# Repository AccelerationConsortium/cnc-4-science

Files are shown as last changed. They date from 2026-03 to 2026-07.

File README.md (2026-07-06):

<h1>cnc-4-science</h1>

<table>
  <tr>
    <td align="center" width="50%">
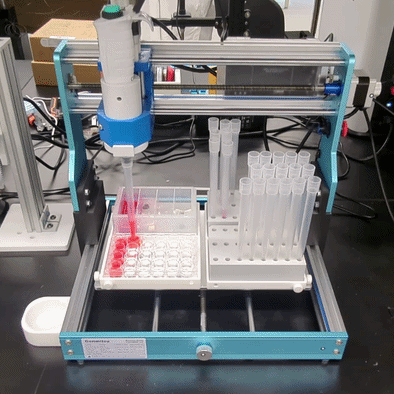
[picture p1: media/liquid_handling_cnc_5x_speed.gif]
Liquid handling demo (5x speed) — click to watch full video
      
      <br/><sub><a href="examples/liquid_handling/">Liquid handling</a> · <a href="https://youtu.be/hJAHL1_uhBs">full video</a></sub>
    </td>
    <td align="center" width="50%">
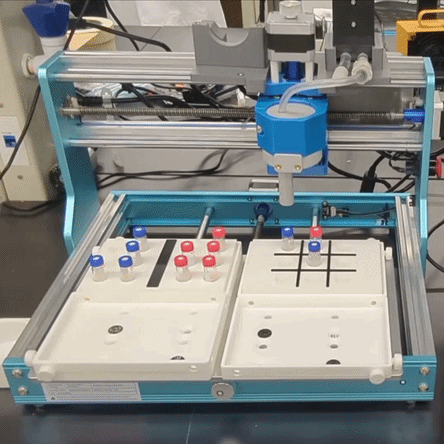
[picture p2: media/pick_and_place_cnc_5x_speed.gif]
Pick-and-place demo (5x speed) — click to watch full video
      
      <br/><sub><a href="examples/vacuum_pick_and_place/">Pick and place</a> · <a href="https://youtu.be/-8ptOuS6o5s">full video</a></sub>
    </td>
  </tr>
</table>

`cnc-4-science` is a Python control library for **low-cost, easy-to-assemble,
open-source GRBL CNC routers** used as the gantry for scientific automation.
The target hardware is the kind of CNC a scientist can buy off the shelf for
a few hundred dollars, put together over a weekend, modify with 3D-printed
parts, and drive from Python — no proprietary controller, no vendor SDK, no
custom firmware. The reference examples in this repo run on a Genmitsu
3018-PROVer V2, but the library is GRBL-generic and works on any equivalent
machine.

It's the foundation for building things like **liquid handling** and
**pick-and-place of vials / consumables / small parts** (the two shipped
examples), and any other workflow that fits the pattern "move this tool to
that well and do something." Each module is built around a 3-step workflow:

| 1. Install a tool | 2. Configure the deck | 3. Write the workflow in Python |
| --- | --- | --- |
| Design and install your instrument on the CNC carriage -- a pipette, a vacuum gripper, a fraction needle, whatever the workflow needs. The mechanical interface is a 3D-printed bracket; the rest is up to the tool. | Decide what labware and external modules sit on the deck and where. Describe it in YAML -- standard SBS plates and tipracks via [Opentrons](https://labware.opentrons.com/#/create) definitions, or open / custom JSON for larger external modules that don't fit the SBS footprint. | Write a Python protocol against `cnc_machine_core` and a thin tool wrapper. The two YAML files (`tools/cnc_config.yaml` + `tools/<tool>_config.yaml`) hold every setup-specific number; the protocol stays portable. |

```bash
pip install cnc-4-science
```

See [`examples/README.md`](examples/README.md) for the standard 3-step user
journey every example follows. To bootstrap a brand-new CNC module with an
LLM coding agent, point it at [`examples/AGENTS.md`](examples/AGENTS.md) --
it documents the directory layout, config schema, and tool-wrapper contract
that every example follows.

---

## Reference applications

| Example | Tool | Workflow | Sample workflow video |
| --- | ---- | --- | --- |
| [`hello_cnc/`](examples/hello_cnc/) | Stock spindle | Home, move, spindle on/off — the hardware smoke test | |
| [`liquid_handling/`](examples/liquid_handling/) | Sartorius Picus 2 pipette | Serial dilution across a 24-well plate | [YouTube](https://youtu.be/hJAHL1_uhBs) |
| [`vacuum_pick_and_place/`](examples/vacuum_pick_and_place/) | Vacuum gripper (spindle-driven) | Physical tic-tac-toe — CLI + optional browser UI | [YouTube](https://youtu.be/-8ptOuS6o5s) |

---

## Quick start

```bash
# 1. Pick an example and read its README + ASSEMBLY_INSTRUCTIONS.md.
#    Order/print the parts and assemble the hardware.

# 2. From the example folder:
python -m venv .venv
.\.venv\Scripts\Activate.ps1     # Windows
# source .venv/bin/activate      # Linux / macOS
pip install -r requirements.txt

# 3. Edit tools/cnc_config.yaml (COM port, travel bounds) and the tool config.
#    See docs/SETUP.md §0 for how to find the serial port on Windows / macOS / Linux
#    and how to measure your CNC's travel envelope.

# 4. Run the protocol.
python protocols/<name>.py
```

> First time setting up a new CNC? Run
> [`examples/hello_cnc/hello_cnc.py`](examples/hello_cnc/) once to verify the
> gantry homes, jogs, and toggles the spindle. You don't need to re-run it
> for every protocol.
>
> Each example's `tools/cnc_config.yaml` ships with `z_heights:` calibrated
> for the reference build in its `ASSEMBLY_INSTRUCTIONS.md`. If your build
> differs, remeasure by hand — see
> [docs/SETUP.md §4](docs/SETUP.md#4-calibrate-z-heights).

> **New to the library?** Read [docs/SETUP.md](docs/SETUP.md) for the
> long-form software walkthrough (deck → labware → toolhead/driver →
> tool offsets → Z calibration → protocol).
>
> **Building your own application?** Copy [`examples/liquid_handling/`](examples/liquid_handling/)
> or [`examples/vacuum_pick_and_place/`](examples/vacuum_pick_and_place/) as
> a template — the conventions are documented in
> [`examples/AGENTS.md`](examples/AGENTS.md).

---

## API reference

### Motion

| Method | Description |
|---|---|
| `home()` / `origin()` | Home and park; or move to origin without homing. |
| `connect()` / `close()` | Open / close the serial connection to the controller. |
| `move_to_point(x, y, z)` | Absolute move (XYZ in mm). |
| `move_to_point_safe(x, y, z)` | Raise Z to clearance, move XY, lower Z. Prevents collisions with labware. |
| `move_to_point_safe_orthogonal(x, y, z, waypoint, axis_order)` | One-axis-at-a-time waypoint move (`yxy`, `xyx`, `xyxy`, `yxyx`). |
| `move_to_location(location, index)` | Move to a named position from `location_status.yaml`. |
| `spindle_on(rpm)` / `spindle_off()` | `M3` / `M5`. Doubles as the on/off for vacuum or solenoid tools wired to the spindle terminals. |
| `is_alarm()` / `recover_if_alarm()` | Alarm-state check + auto-rehome. Called internally before every move. |

### Deck and labware

The `cnc_deck` module provides `Well`, `Labware`, and `Deck` objects for
coordinate resolution:

```python
from cnc_machine_core import Deck
from opentrons_shared_data.labware import load_definition

deck = Deck("cnc_4_slot_deck")                               # built-in 4-slot deck (Genmitsu 3018)

# Standard SBS labware: load by Opentrons load name (no JSON file of your own).
plate = deck.load_labware_definition(
    "1", load_definition("corning_96_wellplate_360ul_flat", 1)
)

# Or a custom JSON for non-SBS gear (see custom_labware/ in the examples):
# plate = deck.load_labware("1", "custom_labware/my_rack.json")

x, y, z = plate["A1"].position()                             # absolute CNC coordinates
```

Protocols add the tool's XY offset at the call site —
`plate["A1"].position(offset=tool.offset)` — see
[`examples/liquid_handling/protocols/serial_dilution_demo.py`](examples/liquid_handling/protocols/serial_dilution_demo.py)
or [`examples/vacuum_pick_and_place/game_session.py`](examples/vacuum_pick_and_place/game_session.py)
for the live pattern.

Built-in decks — pick one explicitly (there is no default; the CNC footprint
should be visible at the call site):

- `cnc_4_slot_deck` — standard 4-slot (2×2), sized for the Genmitsu
  3018-PROVer V2 (~300×180 mm bed). Larger CNCs (3040, 6040, …) will likely
  want a custom deck with more slots — copy the JSON and re-measure the
  slot corners.
- `cnc_1_slot_deck` — single open slot at origin (no labware required)

Labware definitions are created with the
[Opentrons Labware Creator](https://labware.opentrons.com/#/create) — only
the XY well coordinates are used. Z heights are calibrated empirically per
(tool, labware, action) because they depend on the tool mount and labware
seating, not the labware geometry alone. See
[docs/SETUP.md §4](docs/SETUP.md#4-calibrate-z-heights).

### Direct positioning (no labware)

For simple setups, use the open deck and move to raw coordinates:

```python
from cnc_machine_core import Deck

deck = Deck("cnc_1_slot_deck")
cnc.move_to_point_safe(x=100, y=50, z=-20)
```

Regular grids without named wells can be described in YAML and addressed by
index via `move_to_location()`:

```yaml
vial_rack:
  num_x: 2          # columns
  num_y: 4          # rows
  x_origin: 166.5
  y_origin: 125
  z_origin: 0
  x_offset: 36
  y_offset: -36
```

The location index walks a full column before advancing.

vial_rack

### Deck state

The `deck_state` module tracks per-well status across all slots with YAML
persistence:

```python
from cnc_machine_core import DeckState

ds = DeckState()
ds.init_wells_from_labware("1", plate)
ds.init_from_preset({"1": {"A1": "sample"}})
ds.set_status("1", "A1", "processed")                # auto-saves
loc = ds.find_next(["1", "2"], "sample")             # ("1", "A2")
ds.count(["1"], "processed")
ds.summary()
```

Status strings are application-defined. A sample preset is in
[`examples/liquid_handling/deck_preset.yaml`](examples/liquid_handling/deck_preset.yaml).

### Z calibration

Z heights live in `tools/cnc_config.yaml` under `z_heights:` and are measured
empirically per `(tool, labware, action)` — see
[docs/SETUP.md §4](docs/SETUP.md#4-calibrate-z-heights). Each shipped example
includes calibrated values for its reference build; remeasure by hand if
yours differs.

### Tool wrapper contract

Every tool class follows the same shape, so the protocols read the same way
across examples:

```python
class MyTool:
    def __init__(self, cnc_machine, tool_config):
        self.cnc = cnc_machine
        self.offset = tool_config.get("offset", {"x": 0, "y": 0, "z": 0})
        # extract parameters from tool_config["parameters"]
```

See
[`examples/liquid_handling/tools/picus_pipette.py`](examples/liquid_handling/tools/picus_pipette.py)
for a wrapper around a vendor serial driver, and
[`examples/vacuum_pick_and_place/tools/vacuum_gripper.py`](examples/vacuum_pick_and_place/tools/vacuum_gripper.py)
for a wrapper that drives the CNC's spindle terminals directly (no separate
serial port).

---

## Authors and acknowledgements

Authors: Owen Melville, Kelvin Chow.

CNC-based scientific instruments inspired by the
[Keith Brown Lab](https://sites.bu.edu/kablab/) [[1]] [[2]].

[1]: https://doi.org/10.1039/D4MH00797B
[2]: https://doi.org/10.1016/j.ohx.2024.e00601

## License

GNU General Public License v3.0 or later. See [LICENSE](docs/LICENSE).

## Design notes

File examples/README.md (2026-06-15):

# Examples

Reference projects that exercise `cnc_machine_core` end-to-end. Use these as
**templates** when building your own application — copy the closest match and
edit it.

| Example | Hardware | Software |
| --- | --- | --- |
| [`hello_cnc/`](hello_cnc/) | [ASSEMBLY_INSTRUCTIONS.md](hello_cnc/ASSEMBLY_INSTRUCTIONS.md) (~1 hr) — base CNC only | [README](hello_cnc/README.md) — **first-time CNC sanity check** |
| [`liquid_handling/`](liquid_handling/) | [ASSEMBLY_INSTRUCTIONS.md](liquid_handling/ASSEMBLY_INSTRUCTIONS.md) (~1 hr) | [README](liquid_handling/README.md) |
| [`vacuum_pick_and_place/`](vacuum_pick_and_place/) | [ASSEMBLY_INSTRUCTIONS.md](vacuum_pick_and_place/ASSEMBLY_INSTRUCTIONS.md) (~1 hr) | [README](vacuum_pick_and_place/README.md) |

## Standard user journey

Every example follows the same 3-step flow — pick one and follow its README:

1. **Hardware setup (~1 hr)** — order/print parts (BOM in `ASSEMBLY_INSTRUCTIONS.md`),
   wire the tool, mount the deck.
2. **Software setup** — `python -m venv .venv` → activate → `pip install -r requirements.txt`.
3. **Configure & run** — edit `tools/cnc_config.yaml` (COM port, bounds) and the
   tool config, then run the protocol in `protocols/`.

> [`hello_cnc/`](hello_cnc/) is a **first-time CNC sanity check** (homes,
> jogs, toggles the spindle) — run it once when you set up a new machine.
> The other examples don't depend on it.
>
> The `z_heights:` shipped in each example's `cnc_config.yaml` are calibrated
> for the reference build in its `ASSEMBLY_INSTRUCTIONS.md`. If you reproduce
> that build exactly, leave them alone; if anything differs (tip length, deck
> shim, mount), remeasure by hand and edit `z_heights:` — see
> [docs/SETUP.md §4](../docs/SETUP.md#4-calibrate-z-heights).

To create a new example, follow [AGENTS.md](AGENTS.md) — it documents the
shared layout, config schema, driver-class pattern, and the conventions all
of the above follow.

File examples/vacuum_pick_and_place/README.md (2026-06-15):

# Vacuum Pick-and-Place — Physical Tic-Tac-Toe (CLI)

Plays tic-tac-toe on a real 3×3 board using a CNC gantry and a vacuum gripper.
Pieces are picked from a storage rack (X and O reservoirs) and placed on the
game board, one move at a time. The same gripper returns every piece to
storage at end-of-game.

Two-player or 1-player vs AI (Easy / Medium / Hard).

This example doubles as a **template for any vacuum-driven pick-and-place
workflow** — the gripper is just a thin wrapper around the CNC's spindle
output (M3/M5), so swapping in any electromagnet, gripper, or solenoid that
the controller can switch is a one-file change.

---

## 1. Hardware setup

See [ASSEMBLY_INSTRUCTIONS.md](ASSEMBLY_INSTRUCTIONS.md) for the full BOM,
print list, wiring, and step-by-step build. Come back here when the gantry is
mounted, the deck is squared, the vacuum gripper is wired, and the pump turns
on when GRBL sends `M3`.

## 2. Software setup

```bash
# 1. Create + activate a virtual environment
python -m venv .venv
.\.venv\Scripts\Activate.ps1     # Windows
# source .venv/bin/activate      # Linux / macOS

# 2. Install dependencies
pip install -r requirements.txt
```

Edit the two config files in [`tools/`](tools/):

- [`tools/cnc_config.yaml`](tools/cnc_config.yaml) — CNC COM port, travel bounds, Z heights, deck layout.
- [`tools/vacuum_config.yaml`](tools/vacuum_config.yaml) — vacuum RPM, settle delays, XY offset. **No separate port** — the vacuum pump is wired into the GRBL spindle output, so it shares the CNC's serial connection.

> **Finding the CNC COM port.** The GRBL board enumerates as a USB-to-serial
> device when plugged in. Unplug, list the ports, plug it back in, and list
> again — the new entry is the CNC.
>
> - **Windows**: `Get-CimInstance Win32_SerialPort | Select DeviceID, Name`
>   in PowerShell, or open Device Manager → *Ports (COM & LPT)* and look
>   for `USB-SERIAL CH340 (COMx)` / `Silicon Labs CP210x (COMx)`.
> - **macOS**: `ls /dev/tty.* | grep -Ei 'usbserial|wchusbserial'`. CH340
>   boards may need the [WCH driver](https://www.wch-ic.com/downloads/CH34XSER_MAC_ZIP.html).
> - **Linux / Raspberry Pi**: `ls /dev/ttyUSB* /dev/ttyACM*`. Add your user
>   to the `dialout` group to avoid `sudo`.
>
> Full walkthrough + driver links: [docs/SETUP.md §0](../../docs/SETUP.md#finding-the-serial-port-windows--macos--linux).

> Set `virtual: true` in `cnc_config.yaml` to dry-run the protocol without
> any hardware connected.

> The shipped `z_heights:` (`pick: -21.0`, `place: -19.0`) are calibrated for
> the reference build in [ASSEMBLY_INSTRUCTIONS.md](ASSEMBLY_INSTRUCTIONS.md).
> If your build differs, remeasure by hand — jog Z until the suction cup just
> kisses the top of a storage piece (→ `pick`) and just above a board cell
> rim (→ `place`), then edit `z_heights:`. See
> [docs/SETUP.md §4](../../docs/SETUP.md#4-calibrate-z-heights).

## 3. Run

```bash
python protocols/tic_tac_toe.py
```

The CLI prompts for game mode and accepts cell labels `A1`..`C3`. Commands
during play:

| Input | Effect |
| --- | --- |
| `A1`..`C3` | Place at that cell |
| `reset` | Return every placed piece to storage |
| `quit` | Exit; optionally reset board first |

Deck state is auto-saved to `output/deck_state.yaml` after every move, so
a crashed game resumes from the last known state.

### Optional: browser UI

A lightweight FastAPI frontend drives the same `GameSession` as the CLI (same
lock, same hardware handles, same state) — you cannot accidentally drive the
gantry from both at once.

```bash
uvicorn web.app:app --host 0.0.0.0 --port 8000
```

Then open <http://localhost:8000/>. 3×3 clickable board with mode / difficulty
/ symbol selectors, reset button, AI peek-and-play handshake (board flashes
the next CNC move before the gantry executes), and a collapsed debug bar with
the API request log. `virtual: true` works exactly the same way — the browser
drives the full game loop, just without any actual motion.

---

## Reference

### Deck layout

| Slot | Position | Role | Labware |
| ---- | --- | --- | --- |
| 1 | front-left  | *(empty)*  | |
| 2 | front-right | *(empty)*  | |
| 3 | back-left | `storage`  | `storage_15_tuberack_100ul` |
| 4 | back-right  | `gameboard`| `gameboard_15_tuberack_100ul` |

Storage rack (slot 3): O pieces in columns 1-2, X pieces in columns 4-5
(see `STORAGE_WELLS` in [game_logic.py](game_logic.py)).

Game board (slot 4): 3×3 play area occupies columns 2-4 of the 15-well rack
(see `BOARD_WELL_MAP` in [game_logic.py](game_logic.py)).

Slot assignment lives in [tools/cnc_config.yaml](tools/cnc_config.yaml) under
`deck:` — change it there, not in the protocol.

### What's different from the liquid handling demo

| Aspect | Liquid handling | This example |
| --- | --- | --- |
| Tool | Sartorius Picus 2 pipette | Vacuum gripper (suction cup on spindle) |
| Tool comms | Separate serial port (`COM3`) | **None** — uses CNC's spindle output |
| Tool wrapper | [`PicusPipette`](../liquid_handling/tools/picus_pipette.py) calls vendor driver | [`VacuumGripper`](tools/vacuum_gripper.py) calls `cnc.spindle_on()` / `cnc.spindle_off()` |
| Tool config | port, baud, volumes | RPM, settle delays (no port) |
| Labware | Opentrons standard + custom tiprack | Two custom 15-well racks (storage + board)  |
| Workflow | Linear (prefill → dilute) | **Interactive** — CLI prompts for moves |

### Directory layout

```
vacuum_pick_and_place/
├── README.md
├── ASSEMBLY_INSTRUCTIONS.md
├── requirements.txt
├── game_logic.py                       # board + AI (pure Python, no CNC)
├── game_session.py                     # shared state machine (CLI + web)
├── app_runtime.py                      # config loading + CNC/gripper bootstrap
├── protocols/
│   └── tic_tac_toe.py                  # CLI entry point (thin loop over GameSession)
├── web/
│   ├── app.py                          # FastAPI: /api/state | /start | /move | /ai-move | /reset
│   └── static/
│       ├── index.html
│       ├── game.js
│       └── style.css
├── tools/
│   ├── cnc_config.yaml                 # CNC + deck layout + Z heights
│   ├── vacuum_config.yaml              # vacuum: RPM, delays, offset
│   └── vacuum_gripper.py               # VacuumGripper wrapper (uses CNC spindle)
├── presets/
│   └── ttt_preset.yaml                 # initial deck state (X/O storage, empty board)
├── custom_labware/
│   ├── storage_15_tuberack_100ul.json
│   └── gameboard_15_tuberack_100ul.json
└── output/                             # state files written here at runtime
```

### Using this as a template

To adapt for a different vacuum/spindle-switched tool:

1. **Copy this folder** to a new directory.
2. **Edit `tools/vacuum_gripper.py`** if your "tool" semantics differ (e.g.
   electromagnet → rename methods to `magnet_on` / `magnet_off`, keep the
   `cnc.spindle_on/off` underneath).
3. **Add a tool config.** Update `tools/vacuum_config.yaml` with the on-value
   (RPM / PWM duty), any settle delays, and the XY/Z mount offset.
4. **Edit `cnc_config.yaml`.** Update `deck:` slot roles + labware comments
   to match your deck. Measure Z heights by hand (jog with a GRBL UI like
   [Candle](https://docs.sainsmart.com/article/bj9o96wcbc-how-to-set-up-use-candle-for-multiple-operations)
   or `cnc.move_to_point(...)` from a Python shell) and write them into
   `z_heights:` — see [docs/SETUP.md §4](../../docs/SETUP.md#4-calibrate-z-heights).
5. **Write your protocol** in `protocols/`. The `_pick_and_place()` helper in
   [game_session.py](game_session.py) is a one-screen reference. If you also
   want a web UI, copy [web/app.py](web/app.py) — the FastAPI layer is
   ~100 lines and reuses whatever `GameSession`-style state machine you build.

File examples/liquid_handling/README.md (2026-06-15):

# Liquid Handling — Serial Dilution (Sartorius Picus 2)

1:2 serial dilution across a 24-well plate using a Sartorius **Picus 2** 5000 µL pipette on a Genmitsu CNC machine.

This folder doubles as a **template** for building your own CNC-based protocols — copy it, swap the tool, edit the configs.

- **Phase 1 — Prefill.** Pick up a tip, prefill 23 wells (`B1..D6`) with diluent from reservoir A2 (batched aspirations), discard tip.
- **Phase 2 — Dilute.** Pick up a new tip, transfer stock from reservoir A1 into plate A1, then serial-dilute column-by-column (`A1→B1→…→D6`) with a mix per step.

Default volumes (1100 µL prefill / 2200 µL transfer) give a 2:1 mixing ratio per step (each well ≈ 67% of previous).

---

## 1. Hardware setup

See [ASSEMBLY_INSTRUCTIONS.md](ASSEMBLY_INSTRUCTIONS.md) for the full BOM,
print list, wiring, and step-by-step build. Come back here when the gantry is
mounted, the deck is squared, and the Picus is clamped into its holster on
the spindle carriage.

## 2. Software setup

```bash
# 1. Create + activate a virtual environment
python -m venv .venv
.\.venv\Scripts\Activate.ps1     # Windows
# source .venv/bin/activate      # Linux / macOS

# 2. Install dependencies
pip install -r requirements.txt
```

Edit the two config files in [`tools/`](tools/):

- [`tools/cnc_config.yaml`](tools/cnc_config.yaml) — CNC COM port, travel bounds, Z heights, deck layout.
- [`tools/picus_config.yaml`](tools/picus_config.yaml) — Picus COM port (separate USB device from the CNC), mounting offset, default volumes.

> **Finding the COM ports.** The CNC and the Picus pipette each enumerate as
> their own USB-to-serial device, so you need two different `com_port:`
> values. The reliable way to identify which is which is to unplug one of
> them, list the ports, plug it back in, and list again — the new entry is
> the device you just plugged in.
>
> - **Windows**: `Get-CimInstance Win32_SerialPort | Select DeviceID, Name`
>   in PowerShell, or open Device Manager → *Ports (COM & LPT)* and look
>   for `USB-SERIAL CH340 (COMx)` / `Silicon Labs CP210x (COMx)`.
> - **macOS**: `ls /dev/tty.* | grep -Ei 'usbserial|wchusbserial'`. CH340
>   boards may need the [WCH driver](https://www.wch-ic.com/downloads/CH34XSER_MAC_ZIP.html).
> - **Linux / Raspberry Pi**: `ls /dev/ttyUSB* /dev/ttyACM*`. Add your user
>   to the `dialout` group to avoid `sudo`.
>
> Full walkthrough + driver links: [docs/SETUP.md §0](../../docs/SETUP.md#finding-the-serial-port-windows--macos--linux).

> Set `virtual: true` in `cnc_config.yaml` to dry-run the protocol without
> any hardware connected.

> The shipped `z_heights:` are calibrated for the reference build in
> [ASSEMBLY_INSTRUCTIONS.md](ASSEMBLY_INSTRUCTIONS.md). If your build differs
> (different tip length, deck shim, mount), remeasure them by hand and edit
> the `z_heights:` block — see [docs/SETUP.md §4](../../docs/SETUP.md#4-calibrate-z-heights).

## 3. Run

```bash
python protocols/serial_dilution_demo.py
```

Final deck state is written to `output/deck_state.yaml`.

---

## Reference

### Deck layout

| Slot | Position | Role | Labware |
| ---- | --- | --- | --- |
| 1 | front-left  | `plate` | `corning_24_wellplate_3.4ml_flat` |
| 2 | front-right | `tips` | `sartorius_24_tiprack_5000ul` |
| 3 | back-left | `reservoir` | `opentrons_tough_4_reservoir_72ml` (A1 = stock, A2 = diluent) |
| 4 | back-right  | `waste` | `sartorius_24_tiprack_5000ul` |

Slot assignment lives in [tools/cnc_config.yaml](tools/cnc_config.yaml) under `deck:` — change it there, not in the protocol.

### Directory layout

```
liquid_handling/
├── README.md
├── ASSEMBLY_INSTRUCTIONS.md
├── requirements.txt
├── protocols/
│   └── serial_dilution_demo.py     # the protocol (main entry point)
├── tools/
│   ├── cnc_config.yaml             # CNC + deck layout + Z heights
│   ├── picus_config.yaml           # Picus pipette: port, offset, volumes
│   ├── picus_pipette.py            # PicusPipette wrapper (used by protocols)
│   └── picus_driver.py             # vendored low-level Picus 2 driver
├── deck_preset.yaml                # initial deck state (well statuses)
├── custom_labware/
│   └── sartorius_24_tiprack_5000ul.json
└── output/                         # state files written here at runtime
```

### Using this as a template

To adapt for a different tool or protocol:

1. **Copy this folder** to a new directory (e.g. `examples/peristaltic_pump/` or your own repo).
2. **Replace the driver.** Drop your vendor driver into `tools/` (e.g. `pump_driver.py`) and write a thin wrapper (`tools/pump.py`) exposing the methods your protocol needs.
3. **Add a tool config.** Create `tools/<tool>_config.yaml` with the tool's serial port, mounting offset, and any tool-specific parameters.
4. **Edit `cnc_config.yaml`.** Update `deck:` slot roles + labware comments to match your deck. Measure Z heights by hand (jog with a GRBL UI like [Candle](https://docs.sainsmart.com/article/bj9o96wcbc-how-to-set-up-use-candle-for-multiple-operations) or `cnc.move_to_point(...)` from a Python shell) and write them into `z_heights:` — see [docs/SETUP.md §4](../../docs/SETUP.md#4-calibrate-z-heights).
5. **Write your protocol** in `protocols/`. Load the two configs at the top and use the tool wrapper. The dilution demo is a worked reference.

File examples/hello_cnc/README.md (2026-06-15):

# Hello CNC

The hardware smoke test. Run this **right after assembling the machine** and
**before any protocol** to verify the serial connection, homing, a basic
movement, spindle on/off, and the work-zero return.

If this passes, your CNC + COM port + bounds + Python install are all good
and you can move on to a real protocol like
[liquid_handling/](../liquid_handling/) or
[vacuum_pick_and_place/](../vacuum_pick_and_place/).

For the hardware build itself (~1 hour), see
[ASSEMBLY_INSTRUCTIONS.md](ASSEMBLY_INSTRUCTIONS.md).

## Run

```bash
# 1. Create + activate a virtual environment (from the repo root)
python -m venv .venv
.\.venv\Scripts\Activate.ps1     # Windows
# source .venv/bin/activate      # Linux / macOS

# 2. Install cnc-4-science
pip install cnc-4-science

# 3. Edit cnc_config.yaml in this folder — set your COM port and travel bounds.
#    Finding the port:
#      Windows  : Get-CimInstance Win32_SerialPort | Select DeviceID, Name
#                 (or Device Manager -> Ports (COM & LPT) -> "USB-SERIAL CH340 (COMx)")
#      macOS    : ls /dev/tty.* | grep -Ei 'usbserial|wchusbserial'
#      Linux/Pi : ls /dev/ttyUSB* /dev/ttyACM*
#    Trick: unplug, run the command, plug in, run again — the new entry is the CNC.
#    Full walkthrough + driver links: docs/SETUP.md §0.
#    For travel bounds, see docs/SETUP.md §0 (Verify your CNC travel bounds).

# 4. Run
python hello_cnc.py
```

**Expected:** the machine homes, moves to vial-rack position 1, spins the
spindle for a moment, returns to the origin, and exits cleanly.

If anything fails, fix `cnc_config.yaml` (port / bounds) and re-run — do not
move on to a real protocol until this passes.

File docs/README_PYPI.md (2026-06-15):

# cnc-4-science

Python control library for **low-cost, easy-to-assemble, open-source GRBL CNC
routers** used as the gantry for scientific automation — liquid handling,
pick-and-place, fraction collection, anything that fits the pattern
"move this tool to that well and do something."

Reference hardware is the Genmitsu 3018-PROVer V2, but the library is
GRBL-generic.

Full docs, hardware build guides, and end-to-end example projects (liquid
handling, vacuum pick-and-place) live on GitHub:
<https://github.com/AccelerationConsortium/cnc-4-science>.

## Install

```bash
pip install cnc-4-science
```

Python 3.9+.

## API at a glance

Public surface is exported from `cnc_machine_core`:

```python
from cnc_machine_core import CNC_Machine, Deck, DeckState
```

### `CNC_Machine` — motion + spindle

| Method | Purpose |
| --- | --- |
| `CNC_Machine.from_config(path, **overrides)` | Construct from a YAML config (`com_port`, `baud_rate`, `bounds`). |
| `connect()` / `close()` | Open / close the GRBL serial connection. |
| `home()` / `origin()` | Home and park; or move to origin without homing. |
| `move_to_point(x, y, z)` | Absolute move (mm). |
| `move_to_point_safe(x, y, z)` | Raise Z to clearance, move XY, lower Z. Avoids deck collisions. |
| `move_to_point_safe_orthogonal(x, y, z, waypoint, axis_order)` | One-axis-at-a-time waypoint move (`yxy`, `xyx`, `xyxy`, `yxyx`). |
| `move_to_location(location, index)` | Move to a named grid position from `location_status.yaml`. |
| `spindle_on(rpm)` / `spindle_off()` | `M3` / `M5`. Also the on/off for vacuum or solenoid tools wired to the spindle terminals. |
| `is_alarm()` / `recover_if_alarm()` | GRBL alarm state check + auto-rehome (called internally before moves).  |

### `Deck` + `Labware` — coordinate resolution

```python
from cnc_machine_core import Deck
from opentrons_shared_data.labware import load_definition

deck = Deck("cnc_4_slot_deck")   # built-in: 4-slot, sized for the Genmitsu 3018
# deck = Deck("cnc_1_slot_deck")   # built-in: open / single slot
# deck = Deck("path/to/my_deck.json")  # custom JSON

# Standard SBS labware by Opentrons load name:
plate = deck.load_labware_definition(
    "1", load_definition("corning_96_wellplate_360ul_flat", 1)
)

# Or a custom JSON for non-SBS gear:
# plate = deck.load_labware("1", "custom_labware/my_rack.json")

x, y, z = plate["A1"].position()                       # absolute machine coordinates
x, y, z = plate["A1"].position(offset=tool.offset)     # apply tool's XY/Z mount offset
```

There is no default deck — pass an explicit name (or path) so the CNC
footprint is visible at the call site.

### `DeckState` — per-well status tracking

```python
from cnc_machine_core import DeckState

ds = DeckState()
ds.init_wells_from_labware("1", plate)
ds.init_from_preset({"1": {"A1": "sample"}})
ds.set_status("1", "A1", "processed")        # auto-saves to YAML
loc = ds.find_next(["1", "2"], "sample")     # ("1", "A2")
ds.count(["1"], "processed")
ds.summary()
```

Status strings are application-defined.

### Minimal config

`cnc_config.yaml`:

```yaml
cnc:
  com_port: COM4          # Windows: COMx | macOS: /dev/tty.usbserial-* | Linux: /dev/ttyUSB0
  baud_rate: 115200
  bounds:
    x: [0, 280]
    y: [0, 180]
    z: [-37, 0]

virtual: false            # true = dry-run; log G-code only, no hardware
```

`bounds:` must match your physical CNC envelope; the shipped values are for
the Genmitsu 3018.

## License

GNU General Public License v3.0 or later.

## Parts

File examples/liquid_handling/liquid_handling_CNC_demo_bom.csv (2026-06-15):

Bill of Materials
Project | Liquid_handling_CNC_demo
Description | Serial dilution using a 3018 CNC and a Sartorius 5000uL Picus 2 pipette
Revision | A
Date | 2026-06-14 00:00:00
Purchased Parts
# | Part Description | Quantity | ~ Cost (USD) | Link | Notes
A1 | Genmitsu 3018- PROVer V2 CNC | 1 | 256 | https://www.amazon.ca/Genmitsu-3018-PROVer-Beginner-Emergency-Stop-Spoilboard/dp/B0CMTJ6CZC | follow assembly manual up to section 3 except for steps 2.4/2.5 for spindle and acrylic panels (https://docs.sainsmart.com/article/appuv0ufmb-3018-prover-v-2)
A2 | Sartorius 5000uL pipette | 1 | 1190 | https://shop.sartorius.com/us/p/picus-2-electronic-single-channel-pipette/LH-747101
A3 | Sartorius 5000uL pipette tips, 100 pk | 1 | 25.4 | https://shop.sartorius.com/us/p/optifit-non-sterile-pipette-tips-bulk-in-a-bag-qty-100/Bagged-Pipette-Tip-150mm
A4 | Opentrons 4-well reservoir | 1 | 6.8 | https://opentrons.com/products/opentrons-tough-72-ml-4-well-reservoir-25-count | min. qty of 25
A5 | Corning 24-well plate | 1 | 3.75 | https://ecatalog.corning.com/life-sciences/b2c/US/en/Microplates/Assay-Microplates/96-Well-Microplates/Costar%C2%AE-Multiple-Well-Cell-Culture-Plates/p/3738 | 24 well SBS plates will likely work for any vendor. Link is min. qty of 100
A7 | M6x10mm flathead screws | 8 | 0 |  | for screwing in deck slots
A8 | M5x25mm panhead screws | 8 | 0 |  | for z-offset spacers
A9 | M5 nuts | 8 | 0 |  | for z-offset spacers
A10 | food colouring | 1 | 0 | https://www.amazon.ca/Club-House-Food-Colour-Preparation/dp/B00HVVNFVW | water based. Pick your colour
3D Printed Parts
# | Part Name | Quantity | Notes
B1 | 100mm-z-spacer.stl | 2 | uses M5 hardware to elevate the XZ carriage
B2 | deck-slot-5mm-offset.stl | 1 | installed in deck slot 1
B3 | deck-slot-standard.stl | 3 | installed in deck slots 2-4
B4 | sartorius-24-tiprack-5000ul.stl | 2 | custom 24-tip rack
B5 | sartorius-5000ul-pipette-tool-holder-a.stl | 1 | two-part toolhead mount that clamps around pipette
B6 | sartorius-5000ul-pipette-tool-holder-b.stl | 1 | two-part toolhead mount that clamps around pipette
B7 | m6-thumb-screw.stl | 8 | for securing labware into deck slots. any M6 screw will work. This was directly modified/printed from here https://www.mcmaster.com/92545A183/
Other Physical Requirements and tools
A computer (Windows / macOS / Linux) with a USB-A port (or necessary dongle) to connect to the CNC over USB serial.
Access to water. If I'm making this explicity requirment, I might be missing out some other requirements
Allen keys and screwdrivers
 |  |  | Author
 |  |  | KC
Changelog
Revision | Description | Date
A | Initial Release | 2026-06-14 00:00:00

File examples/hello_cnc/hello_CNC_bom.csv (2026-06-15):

Bill of Materials
Project | hello_CNC
Description | minimal physical setup for checking hardware installation
Revision | A
Date | 2026-06-14 00:00:00
Purchased Parts |  |  |  |  | Notes
# | Part Description | Quantity | ~ Cost (USD) | Link | follow assembly manual up to section 3 except for steps 2.4/2.5 for spindle and acrylic panels (https://docs.sainsmart.com/article/appuv0ufmb-3018-prover-v-2)
A1 | Genmitsu 3018- PROVer V2 CNC | 1 | 256 | https://www.amazon.ca/Genmitsu-3018-PROVer-Beginner-Emergency-Stop-Spoilboard/dp/B0CMTJ6CZC
Other Physical Requirements
A computer (Windows / macOS / Linux) with a USB-A port (or necessary dongle) to connect to the CNC over USB serial.
Changelog
Revision | Description | Date | Author
A | Initial Release | 2026-06-14 00:00:00 | KC

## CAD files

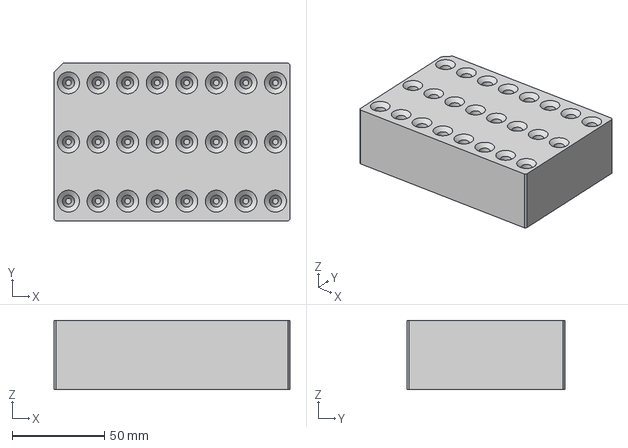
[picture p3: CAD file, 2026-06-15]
examples/liquid_handling/cad/step/sartorius-24-tiprack-5000ul.step
127.7 x 85.5 x 37.5 mm

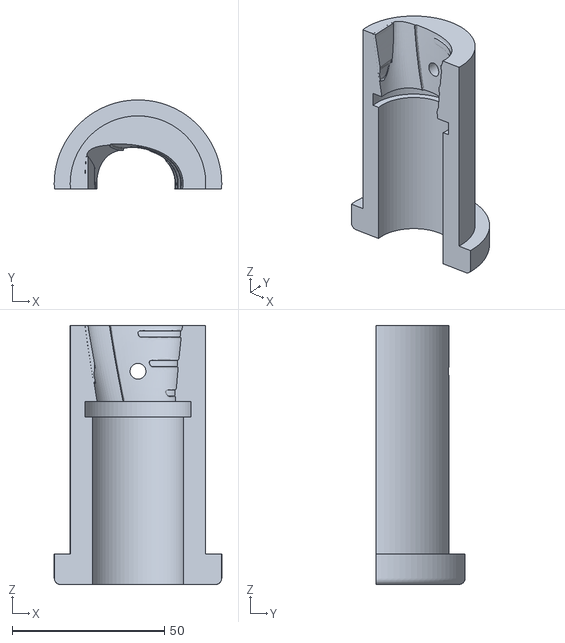
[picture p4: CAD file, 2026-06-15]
examples/liquid_handling/cad/stl/sartorius-5000ul-pipette-tool-holder-b.stl
55.0 x 29.2 x 85.0

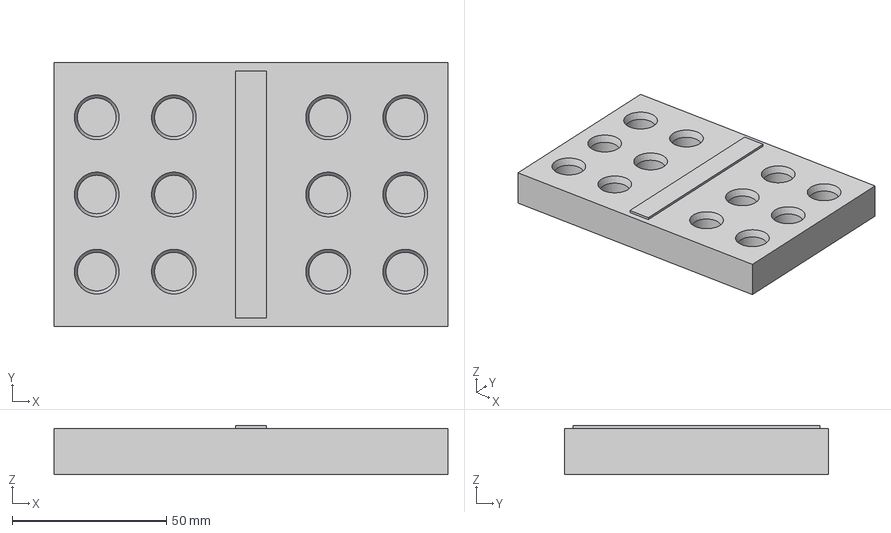
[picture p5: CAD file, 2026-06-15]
examples/vacuum_pick_and_place/cad/step/storage-15-tuberack-100ul.step
127.7 x 85.5 x 16.0 mm

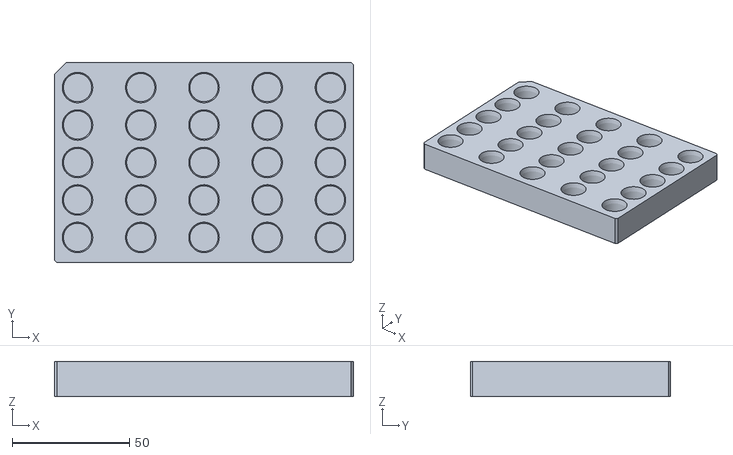
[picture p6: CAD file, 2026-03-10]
src/cnc_machine_core/labware/cad/vialtrayholder_25_tuberack_1000ul.stl
127.7 x 85.5 x 15.0

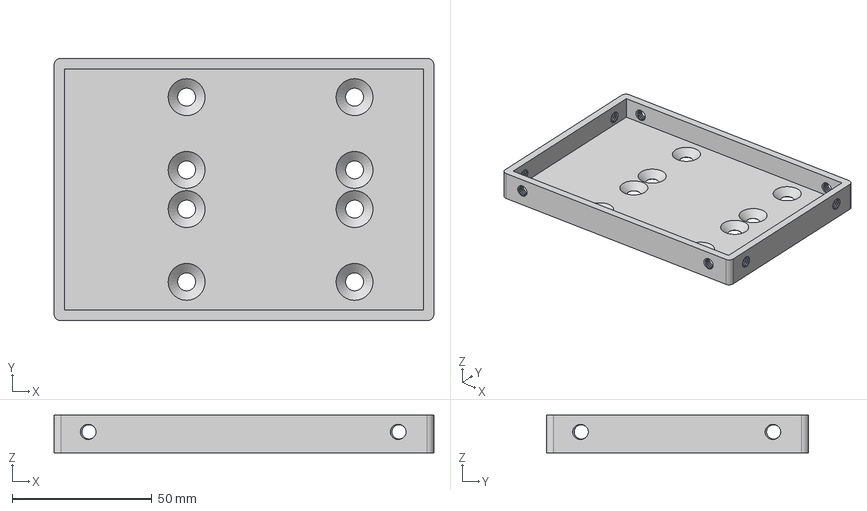
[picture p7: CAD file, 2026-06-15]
examples/liquid_handling/cad/step/deck-slot-standard.step
135.8 x 93.8 x 13.5 mm

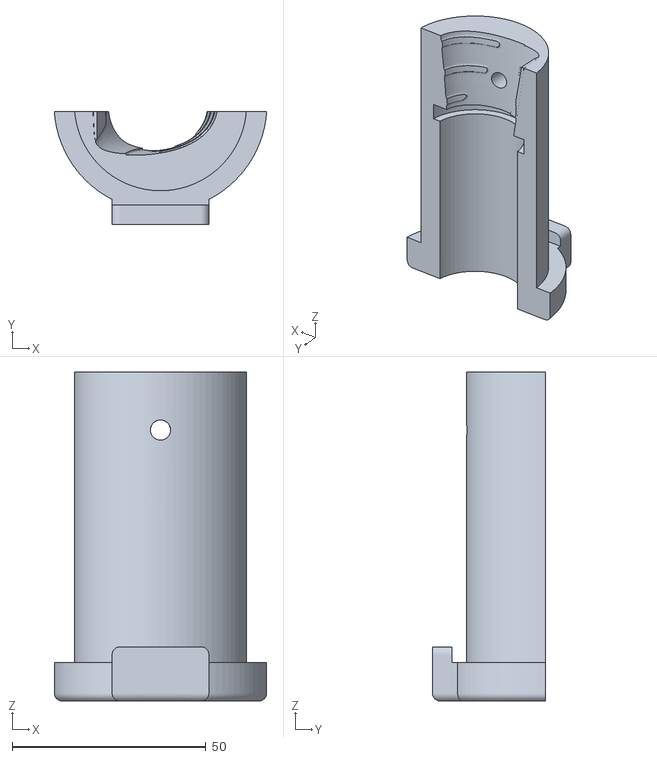
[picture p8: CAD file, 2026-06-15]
examples/liquid_handling/cad/stl/sartorius-5000ul-pipette-tool-holder-a.stl
54.9 x 29.2 x 85.0

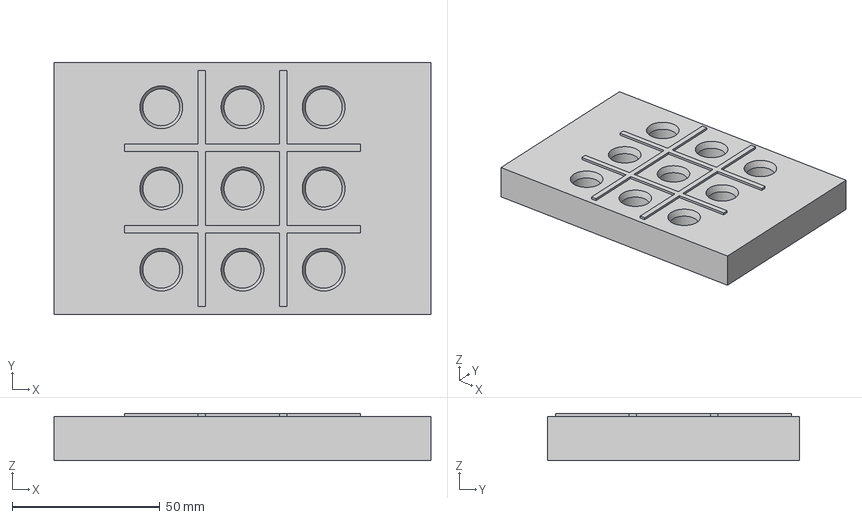
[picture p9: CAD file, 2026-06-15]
examples/vacuum_pick_and_place/cad/step/gameboard-15-tuberack-100ul.step
127.7 x 85.5 x 16.0 mm

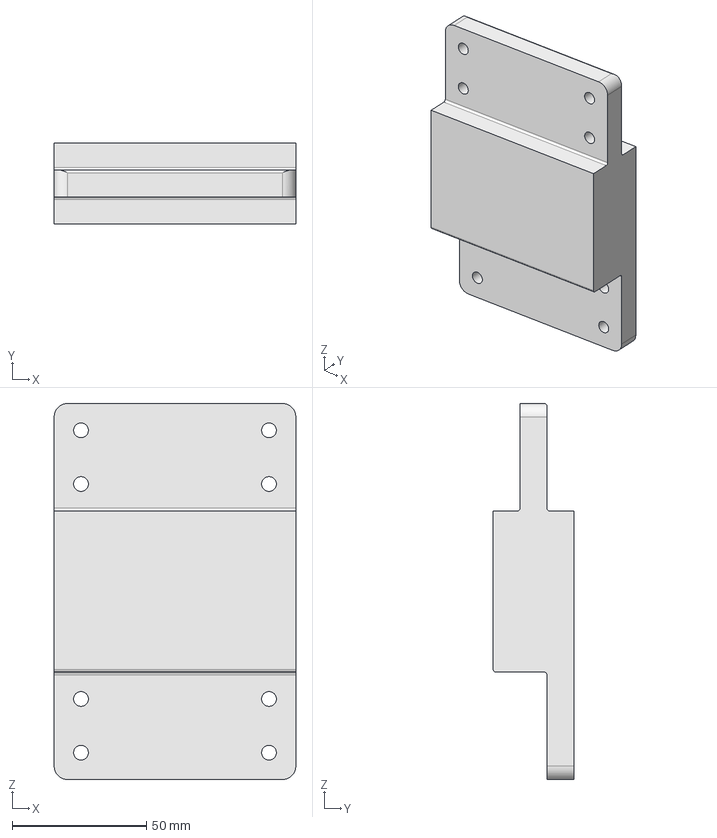
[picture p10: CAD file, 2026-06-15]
examples/liquid_handling/cad/step/100mm-z-spacer.step
90.0 x 30.0 x 140.0 mm

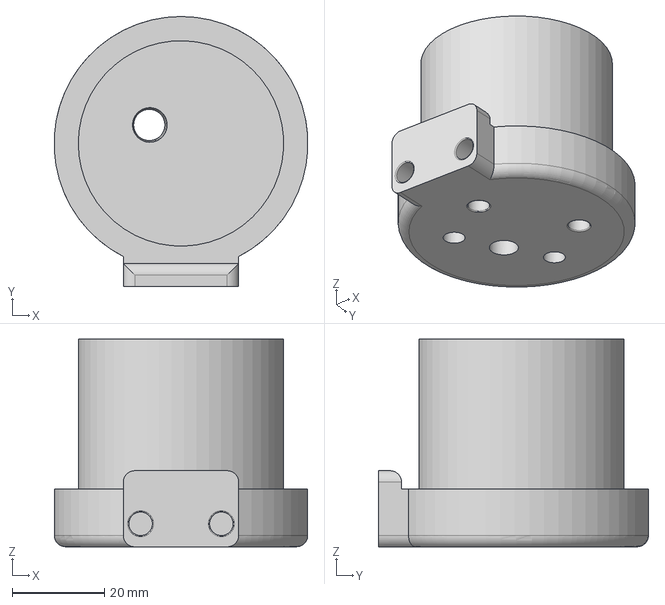
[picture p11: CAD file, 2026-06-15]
examples/vacuum_pick_and_place/cad/step/vacuum-gripper-toolhead-mount.step
54.9 x 58.5 x 45.0 mm

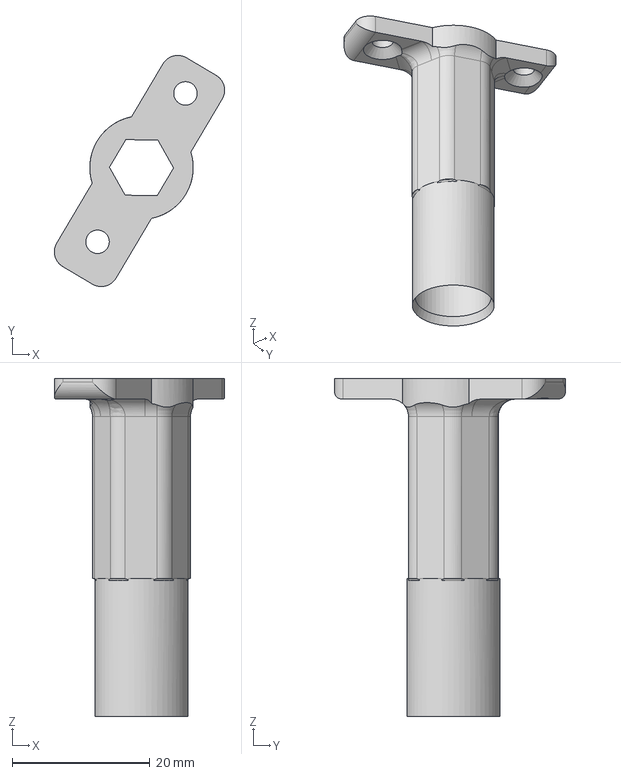
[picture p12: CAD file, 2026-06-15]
examples/vacuum_pick_and_place/cad/step/suction-cup-holder.step
24.7 x 33.5 x 49.0 mm

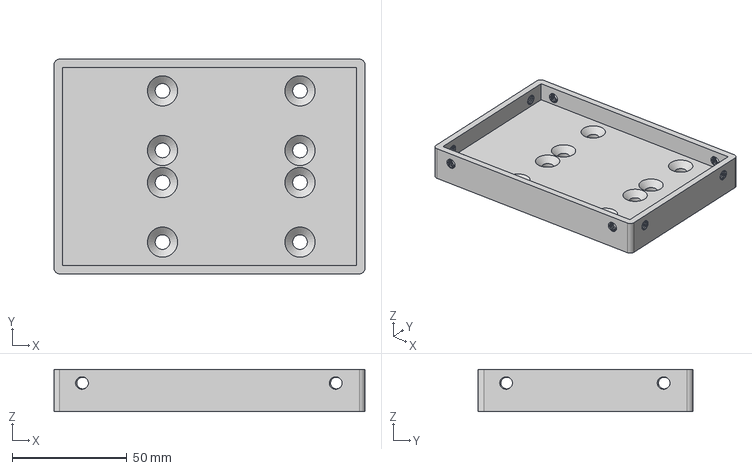
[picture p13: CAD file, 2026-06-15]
examples/liquid_handling/cad/step/deck-slot-5mm-offset.step
135.8 x 93.8 x 18.5 mm

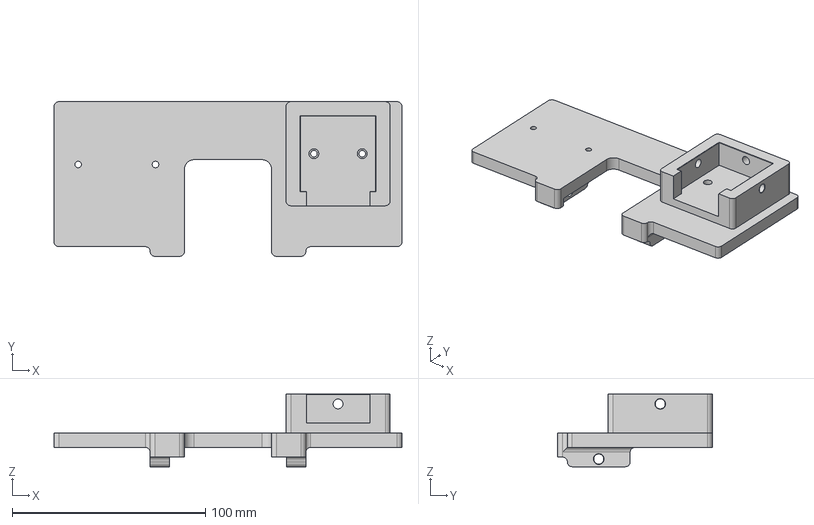
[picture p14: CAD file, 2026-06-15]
examples/vacuum_pick_and_place/cad/step/vacuum-pump-mounting-plate.step
180.0 x 80.0 x 37.5 mm

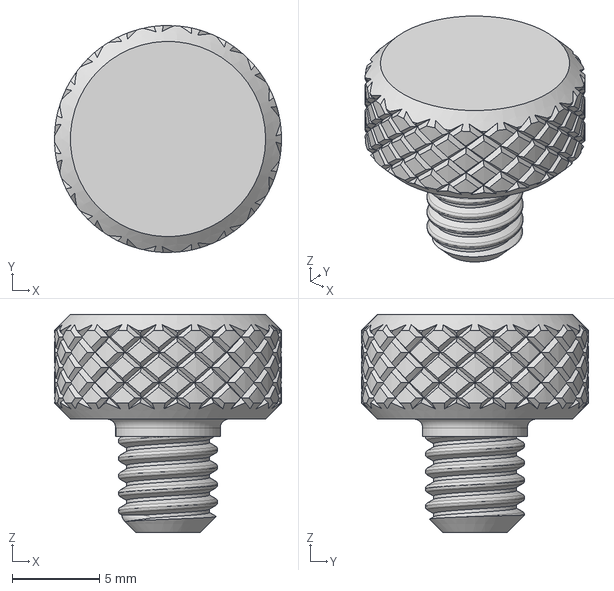
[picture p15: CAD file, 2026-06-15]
examples/liquid_handling/cad/step/m6-thumb-screw.step
13.0 x 13.0 x 12.5 mm

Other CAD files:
examples/liquid_handling/cad/stl/100mm-z-spacer.stl
examples/liquid_handling/cad/stl/deck-slot-5mm-offset.stl
examples/liquid_handling/cad/stl/deck-slot-standard.stl
examples/liquid_handling/cad/stl/m6-thumb-screw.stl
examples/liquid_handling/cad/stl/sartorius-24-tiprack-5000ul.stl
examples/vacuum_pick_and_place/cad/stl/deck-slot-standard.stl
examples/vacuum_pick_and_place/cad/stl/gameboard-15-tuberack-100ul.stl
examples/vacuum_pick_and_place/cad/stl/m6-thumb-screw.stl
examples/vacuum_pick_and_place/cad/stl/storage-15-tuberack-100ul.stl
examples/vacuum_pick_and_place/cad/stl/suction-cup-holder.stl
examples/vacuum_pick_and_place/cad/stl/vacuum-gripper-toolhead-mount.stl
examples/vacuum_pick_and_place/cad/stl/vacuum-pump-mounting-plate.stl
src/cnc_machine_core/labware/cad/vialtrayholder_25_tuberack_1000ul.f3d

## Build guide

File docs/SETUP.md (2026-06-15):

# Setting Up a CNC Machine for a New Application

This guide walks through the end-to-end workflow for turning a bare Genmitsu CNC
into a working instrument for a new experiment. The two examples shipped with
the library cover the two ends of the spectrum:

- [examples/hello_cnc/](../examples/hello_cnc/) — open deck, direct coordinates,
  no labware. The minimum needed to verify the machine moves.
- [examples/liquid_handling/](../examples/liquid_handling/) — full deck layout,
  Opentrons + custom labware, calibrated tool offsets, multi-phase protocol.

The order of operations below is the same one used to build the liquid handling
demo. Follow it from top to bottom for any new application.

---

## 0. Prerequisites

- A homed, working Genmitsu CNC (GRBL firmware over USB serial).
- The COM port / `/dev/tty*` device of the controller — see
  [Finding the serial port](#finding-the-serial-port-windows--macos--linux)
  below.
- The physical XY/Z travel envelope of your machine (mm) — see below.
- Python 3.10+ with `cnc-4-science` installed:
  ```bash
  pip install cnc-4-science
  ```
- A first-pass hardware check before doing anything else:
  ```bash
  python examples/hello_cnc/hello_cnc.py
  ```
  Edit [examples/hello_cnc/cnc_config.yaml](../examples/hello_cnc/cnc_config.yaml)
  first to match your COM port and travel bounds.

### Finding the serial port (Windows / macOS / Linux)

The GRBL board enumerates as a USB-to-serial device when you plug it in
(most hobbyist CNCs ship with a CH340 or CP210x chip). You need to identify
which port belongs to the CNC and put it into the `com_port:` field of
`cnc_config.yaml` for whichever example you're running:

| Example | File to edit |
| --- | --- |
| [hello_cnc](../examples/hello_cnc/) | [`examples/hello_cnc/cnc_config.yaml`](../examples/hello_cnc/cnc_config.yaml) |
| [liquid_handling](../examples/liquid_handling/) | [`examples/liquid_handling/tools/cnc_config.yaml`](../examples/liquid_handling/tools/cnc_config.yaml) — *and* set `com_port:` in [`tools/picus_config.yaml`](../examples/liquid_handling/tools/picus_config.yaml) for the pipette (separate port) |
| [vacuum_pick_and_place](../examples/vacuum_pick_and_place/) | [`examples/vacuum_pick_and_place/tools/cnc_config.yaml`](../examples/vacuum_pick_and_place/tools/cnc_config.yaml) (no separate tool port — the vacuum runs off the GRBL spindle output) |

The reliable trick on any OS is **unplug, list ports, plug in, list again** —
the new entry is the CNC.

**Windows** (PowerShell):

```powershell
# List all serial ports with their hardware names
Get-CimInstance Win32_SerialPort | Select-Object DeviceID, Name, Description

# Or open Device Manager -> "Ports (COM & LPT)" and look for
# "USB-SERIAL CH340 (COMx)" or "Silicon Labs CP210x (COMx)".
```

Put the COM string (e.g. `COM4`) into `com_port:`.

**macOS**:

```bash
# CH340 and CH9102 boards usually show up as /dev/tty.wchusbserial*
# CP210x boards show up as /dev/tty.usbserial-*
ls /dev/tty.* | grep -Ei 'usbserial|wchusbserial|usbmodem'
```

Put the full path (e.g. `/dev/tty.wchusbserial14110`) into `com_port:`.
You may need to install the [WCH CH34x driver](https://www.wch-ic.com/downloads/CH34XSER_MAC_ZIP.html)
on macOS for CH340 boards to appear.

**Linux / Raspberry Pi**:

```bash
ls /dev/ttyUSB* /dev/ttyACM* 2>/dev/null
# After plugging the CNC in, you can also confirm with:
dmesg | tail
# Look for a line like "ch341-uart converter now attached to ttyUSB0".
```

Put the full path (e.g. `/dev/ttyUSB0`) into `com_port:`. Your user must be
in the `dialout` group to access it without `sudo`:

```bash
sudo usermod -aG dialout $USER   # log out / back in to take effect
```

Only one program can hold the serial port at a time — close Candle / UGS /
the Arduino Serial Monitor before running any Python script.

---

### Verify your CNC travel bounds (this is model-specific!)

**The `bounds:` block in `cnc_config.yaml` MUST match your physical machine.**
The shipped configs use the Genmitsu CNC **3018** envelope (X 0..280, Y 0..180,
Z -37..0) because that's the model the liquid handling demo runs on. A 3020,
4040, PROVerXL, etc. will have a completely different envelope, and the
library's bounds-check will silently skip any move outside what you declared
— or worse, you'll declare bounds that exceed the machine and crash the
gantry into a limit switch.

Before editing the YAML, use a GRBL jog UI to *measure* the real travel of
your specific unit:

1. Install [Candle](https://docs.sainsmart.com/article/bj9o96wcbc-how-to-set-up-use-candle-for-multiple-operations)
   (or UGS / bCNC — anything that talks GRBL over the same COM port).
2. Home the machine.
3. Jog X to the positive limit (until it hits the switch or you see resistance),
   read `MPos.X`. Repeat for X negative, Y±, Z±.
4. Subtract a small safety margin (1–3 mm) from each end.
5. Put the resulting numbers into `bounds:` in `cnc_config.yaml`.

Close Candle before running any Python script — only one process can hold the
serial port at a time.

If hello_cnc homes, jogs, and toggles the spindle, the machine is good and you
can start building the application.

---

## 1. Define your deck layout

The deck is the static map from "slot N" to absolute machine coordinates. It is
defined once per physical mounting plate. You almost never edit slot positions
at runtime — they are calibrated to the holes you cut/printed/clamped onto the
CNC bed.

### Two built-in decks

Both shipped definitions are **sized for the Genmitsu 3018-PROVer V2**
(~300×180 mm bed). Larger CNCs (3040, 6040, etc.) will usually want a
custom deck with more / larger slots — copy `cnc_4_slot_deck.json` and
re-measure the slot corners.

There is no default — always pass an explicit deck name (or path) so the
CNC footprint is visible at the call site.

| Definition | Layout | Use case |
| --- | --- | --- |
| `cnc_4_slot_deck` | 2×2 SBS-ish  | Multi-labware protocols on the 3018. |
| `cnc_1_slot_deck` | Open / origin| Single fixture; or pure raw-coordinate use. |

```python
from cnc_machine_core import Deck

deck = Deck("cnc_4_slot_deck")      # 4-slot, Genmitsu 3018 footprint
deck = Deck("cnc_1_slot_deck")      # open / single fixture
deck = Deck("path/to/my_deck.json") # custom JSON
```

### Anatomy of a deck JSON

A deck is a list of slots, each with an absolute `position` (the corner of the
slot in machine XY) and a `boundingBox` (so labware loaded onto it knows where
its origin lives). See
[src/cnc_machine_core/deck/cnc_4_slot_deck.json](../src/cnc_machine_core/deck/cnc_4_slot_deck.json)
for the exact schema. To make a custom deck:

1. Copy `cnc_4_slot_deck.json` and rename it (e.g. `my_3_slot_deck.json`).
2. Edit `locations.slots`: set each slot's `id`, `displayName`, `position`
   `[x, y, z]` in mm (absolute machine coordinates), and `boundingBox` to the
   footprint of whatever labware will sit there (SBS 127.7 × 85.5 mm by
   default).
3. Pass the path to `Deck("path/to/my_3_slot_deck.json")`.

Pick the slot corners by jogging the spindle to the front-left corner of each
physical mounting location and reading the GRBL `MPos`. Record those numbers
in the deck JSON. After this is done, all per-protocol movement is expressed
in *slot* + *well* — you should not be retuning the deck again.

---

## 2. Load labware onto slots

Once the deck exists, each slot gets a piece of *labware* — a JSON file in the
Opentrons format that describes the wells inside that slot relative to its
corner. The library converts to absolute machine coordinates automatically:

```
absolute_well_xyz = slot.position + labware.cornerOffsetFromSlot + well.xyz
```

You have three options for sourcing labware, in order of preference.

### Option A — Standard Opentrons labware (SBS plates, tipracks, reservoirs)

If your container is a normal SBS-format plate / tiprack / reservoir, it
probably already exists in [opentrons-shared-data](https://github.com/Opentrons/opentrons/tree/edge/shared-data/labware/definitions).
Load it by load name with no JSON files of your own:

```python
from opentrons_shared_data.labware import load_definition
from cnc_machine_core import Deck

deck = Deck("cnc_4_slot_deck")
plate_def = load_definition("corning_24_wellplate_3.4ml_flat", 1)
plate = deck.load_labware_definition("1", plate_def)
```

This is what the liquid handling demo does for the 24-well plate and the
4-channel reservoir.

### Option B — Custom labware via the Opentrons Labware Creator

If your container is *SBS-shaped* (127.7 × 85.5 mm footprint) but not a stock
part — a custom 3D-printed tube rack, a sample-specific plate, a tiprack from a
non-Opentrons vendor — generate a JSON for it at
<https://labware.opentrons.com/#/create>:

1. Set the dimensions, well count, well shape, depth, spacing, A1 offset.
2. Export the JSON.
3. Drop it into your project's `custom_labware/` folder.
4. Load it with the path:
   ```python
   plate = deck.load_labware("1", "custom_labware/my_24_tuberack.json")
   ```

This is the [`sartorius_24_tiprack_5000ul.json`](../examples/liquid_handling/custom_labware/sartorius_24_tiprack_5000ul.json)
case in the demo — a custom tiprack matching the Picus tip footprint.

Only the X / Y well coordinates from the JSON are used. **Z heights are *not*
trusted from the labware definition.** In principle Z could be computed as
`slot.z + labware.cornerOffsetFromSlot.z + well.z + tool.offset.z + tip_length`,
but in practice there are too many independently-variable terms (deck shim
thickness, labware seating, tool mounting height, tip length per box) — getting
any one of them wrong by 1 mm crashes the tool. Rather than maintain four
calibration knobs that all have to agree, we collapse them into a single
empirical number per (tool, labware, action) tuple, measured by hand once and
pinned in `tools/cnc_config.yaml`. See step 4.

Access wells by name once loaded:

```python
well = plate["A1"]
x, y, z = well.position()                         # absolute coordinates
x, y, z = well.position(offset={"x": 6.75, "y": -4.0})  # with tool offset

for well in plate.wells():        # iterate in column-major Opentrons order
    cnc.move_to_point_safe(*well.position(offset=tool_offset))
```

### Option C — Non-SBS containers (use `move_to_location` arrays)

If your container doesn't fit SBS — a vial rack you machined yourself, a
custom HPLC tray, a row of beakers on a benchtop fixture — skip the
labware/JSON pipeline entirely and use `move_to_location()` with a YAML grid
definition. See [examples/hello_cnc/location_status.yaml](../examples/hello_cnc/location_status.yaml):

```yaml
vial_rack:
  num_x: 2          # columns
  num_y: 4          # rows
  x_origin: 166.5   # absolute machine X of position 0
  y_origin: 125     # absolute machine Y of position 0
  z_origin: 0
  x_offset: 37.5    # column pitch (measure with calipers)
  y_offset: -36     # row pitch (negative = back-to-front)
```

Then in code:

```python
m = CNC_Machine.from_config("cnc_config.yaml",
                            locations_file="location_status.yaml")
m.move_to_location("vial_rack", 0, safe=True)  # position 0
m.move_to_location("vial_rack", 3, safe=True)  # 4th position (column-major)
```

Indices walk *down a column*, then to the next column (index 0 is
`x_origin, y_origin`, index 1 is one row down, etc).

### Option D — Pure raw coordinates (no labware at all)

For one-off probes, a single fixture, alignment work, or motion debugging,
skip both labware and location grids and use `move_to_point_safe()` directly:

```python
cnc.move_to_point_safe(x=100.0, y=50.0, z=-20.0)
```

This is what `hello_cnc.py`'s line `m.move_to_point(100, 100, -30)` does.
Useful while you're still figuring out what *should* become a labware
definition. Always prefer `_safe` over the bare `move_to_point` — it lifts Z
first, moves XY, then drops Z, which keeps the tool from dragging through
whatever is on the deck.

For motion *between* two crowded slots, also see `move_to_point_safe_orthogonal()`
in the [API reference](../README.md#api-reference) — it lets you specify a
waypoint and axis order to route around obstacles.

---

## 3. Configure the toolhead

The "toolhead" is whatever is bolted to the spindle mount: a pipette, a
camera, a force sensor, a syringe pump, a peristaltic pump, a webcam, a vial
capper. Each tool needs four things:

1. **A communication channel.** A serial port (most common), USB HID, I²C,
   etc.
2. **A driver.** Either vendor-supplied or written by you. Wraps the wire
   protocol in Python methods.
3. **A wrapper class.** A thin Python class that *uses* the driver and exposes
   the high-level actions your protocols need (`aspirate`, `tip_eject`,
   `capture_image`, `dispense_fraction`).
4. **An XY/Z mounting offset.** The tool tip is not at the spindle center.
   The offset captures how far off it is.

### 3.1 Driver

If the vendor publishes a Python driver (PyPI / GitHub), pin a version in
`requirements.txt`. If not, vendor a copy into `tools/` — that's what the
liquid handling demo does with [`tools/picus_driver.py`](../examples/liquid_handling/tools/picus_driver.py).
A driver typically exposes raw operations: open the port, send a command,
parse the response.

### 3.2 Tool wrapper class

Every wrapper follows the same shape:

```python
class MyTool:
    def __init__(self, cnc_machine, tool_config):
        self.cnc = cnc_machine
        self.offset = tool_config.get("offset", {"x": 0, "y": 0, "z": 0})
        # ... extract whatever else the protocol needs from tool_config
        self._driver = None  # constructed in connect()

    def connect(self):
        ...
    def close(self):
        ...

    # High-level verbs the protocol calls:
    def aspirate(self, volume_ul): ...
    def dispense(self, volume_ul): ...
```

[`tools/picus_pipette.py`](../examples/liquid_handling/tools/picus_pipette.py)
is the reference implementation. Two patterns worth copying:

- **Virtual mode**: take a `virtual: bool` flag. In virtual mode, `print()`
  the action and skip the driver. This lets every protocol dry-run without
  hardware.
- **High-level vocabulary**: name methods after what the protocol thinks
  about (`aspirate`, `dispense`, `blow_out`, `tip_eject`), not what the wire
  protocol thinks about (`send_packet`, `cmd_0x07`).

### 3.3 XY/Z tool offset from the spindle origin

The CNC's coordinate frame is centered on the spindle. The actual *tip* of
your tool — pipette nozzle, camera focus point, capper jaw — is mounted
*beside* the spindle, offset by some `(dx, dy, dz)`. Without the offset, you
will pipette into the wall next to your well.

**Measuring the offset:**

1. Jog the CNC so the spindle center is over a known reference point (a
   crosshair, a well A1 with a centered marker, a calibration plate).
2. Read `MPos` → call this `(x_spindle, y_spindle, z_spindle)`.
3. Now jog so the **tool tip** is over the same reference. Read `MPos` →
   `(x_tool, y_tool, z_tool)`.
4. Offset = `(x_tool − x_spindle, y_tool − y_spindle, z_tool − z_spindle)`.
5. Put those numbers under `offset:` in the tool's config YAML.

Then in every protocol move:

```python
x, y, z = plate["A1"].position(offset=pipette.offset)
cnc.move_to_point_safe(x, y, z)
```

The offset moves with the tool wrapper — if you swap tools, you swap configs,
and protocols don't need to change.

### 3.4 Tool config YAML

Each tool gets its own `tools/<tool>_config.yaml` so swapping a tool means
editing one file. Pattern from the demo
([`tools/picus_config.yaml`](../examples/liquid_handling/tools/picus_config.yaml)):

```yaml
toolId: picus_pipette
displayName: Sartorius Picus 2 5000µL Pipette

com_port: COM3            # serial port for the tool itself
default_speed: 5

offset:                   # mm, relative to spindle center
  x: 0.0
  y: 0.0
  z: 0.0

volumes:                  # whatever the protocol needs
  prefill: 1100
  mix: 1200
  tip_max: 5000
```

The CNC config (`cnc_config.yaml`) owns deck layout, bounds, COM port for the
gantry, and Z heights per labware. The *tool* config owns only the tool. Keep
the split clean.

---

## 4. Calibrate Z heights

Once the deck is fixed and the tool is mounted, you still need to know *how
low* to drop Z in each labware. Z depends on at least four independent things:

- The tool's Z offset from the spindle origin (how far the tool sticks down
  past the spindle nose).
- The labware's intrinsic Z (well depth, tiprack tip height, reservoir floor).
- The deck/slot Z (shim thickness, mounting hardware, how flat the bed is).
- The action (`tip_pickup` engages near the top of a tip, `plate_aspirate`
  reaches the well floor — same labware, very different Z).

In theory you could measure each term separately and add them. In practice
that's four chances to be wrong by a millimeter, and a millimeter is the
difference between aspirating from the floor and ramming the pipette through
the plate. The simpler and more reliable approach: ignore the breakdown and
measure the *final* Z empirically per (tool, labware, action), once, then
pin the numbers in `tools/cnc_config.yaml` under `z_heights:`.

### Procedure

With the tool mounted and the deck installed, for each (labware, action) pair:

1. Open a GRBL UI like [Candle](https://docs.sainsmart.com/article/bj9o96wcbc-how-to-set-up-use-candle-for-multiple-operations)
   (or use `CNC_Machine` from a Python REPL, e.g. `cnc.move_to_point(...)`).
2. Move XY over the relevant well — use the labware's well coordinates plus
   your tool offset: `plate["A1"].position(offset=tool.offset)`.
3. Jog Z down in coarse steps (~2 mm), then medium (~0.5 mm), then fine
   (~0.1 mm) until the tool tip kisses the surface you care about
   (tip-pickup engages near the top of a tip; `plate_aspirate` reaches the
   well floor — same labware, different Z).
4. Read the absolute Z off the controller and write it into the
   `z_heights:` block of `tools/cnc_config.yaml`.

Do this once per build. The shipped examples come with `z_heights:` already
filled in for their reference build (see each example's
`ASSEMBLY_INSTRUCTIONS.md`); if your build matches, you don't need to
remeasure. If you replace a tool, reseat labware, or change a shim,
remeasure only the affected entries.

```yaml
z_heights:
  hover: 0.0
  tip_pickup: -35.5
  reservoir: -36.5
  plate_aspirate: -36.5
  plate_dispense: -36.5
```

These are the named Z values the protocol uses. The XY of each well comes
from labware; the Z comes from this block. If you replace a tool or reseat a
labware, remeasure the affected entries.

---

## 5. Write the protocol

Protocols live in `protocols/` and contain *only the workflow logic* — no
serial ports, no labware paths, no Z numbers. Everything sourced from config:

```python
from pathlib import Path
import yaml
from opentrons_shared_data.labware import load_definition
from cnc_machine_core import CNC_Machine, Deck
from tools.picus_pipette import PicusPipette

HERE = Path(__file__).resolve().parent
CNC_CFG  = HERE.parent / "tools" / "cnc_config.yaml"
TOOL_CFG = HERE.parent / "tools" / "picus_config.yaml"

cnc_cfg  = yaml.safe_load(CNC_CFG.read_text())
tool_cfg = yaml.safe_load(TOOL_CFG.read_text())

# 1. Build the machine (deck-aware via cnc_config.yaml)
cnc = CNC_Machine.from_config(CNC_CFG)
deck = Deck(cnc_cfg["deck"]["definition"])
plate = deck.load_labware_definition("1",
            load_definition("corning_24_wellplate_3.4ml_flat", 1))
tips  = deck.load_labware("2", str(HERE.parent / "custom_labware" /
            "sartorius_24_tiprack_5000ul.json"))

# 2. Build the tool
pipette = PicusPipette(com_port=tool_cfg["com_port"],
                       virtual=cnc_cfg.get("virtual", False))

# 3. Run the workflow
cnc.connect(); pipette.connect()
try:
    z = cnc_cfg["z_heights"]
    offset = tool_cfg["offset"]
    for well in plate.wells():
        x, y, _ = well.position(offset=offset)
        cnc.move_to_point_safe(x, y, z["plate_dispense"])
        pipette.dispense(100)
finally:
    pipette.close(); cnc.close()
```

[examples/liquid_handling/protocols/serial_dilution_demo.py](../examples/liquid_handling/protocols/serial_dilution_demo.py)
is a worked version of this pattern.

### Dry-run first

Set `virtual: true` in `cnc_config.yaml` and re-run the protocol. The CNC
class logs every G-code it would emit; the tool wrapper logs every action it
would take. Read the log end-to-end before powering anything on. Then flip
`virtual: false` and run on hardware.

---

## 6. Track deck state (optional)

For protocols that consume / produce wells over time (tip racks emptying,
samples processed, fractions collected), use `DeckState`:

```python
from cnc_machine_core import DeckState

ds = DeckState()
ds.init_wells_from_labware("2", tips)
next_slot, next_well = ds.find_next(["2"], "available")
ds.set_status("2", next_well, "used")
```

Status strings are application-defined. State is auto-persisted to YAML in
`output/`, so a crashed protocol can resume from where it stopped.

---

## Cheat sheet — building a new application from scratch

| Step | What you do | Where it lives |
| ---: | --- | --- |
| 1 | Run `hello_cnc.py` once to verify the gantry | `examples/hello_cnc/` |
| 2 | Copy `examples/liquid_handling/` as template | `your_project/` |
| 3 | Edit deck slot positions (rarely) | custom `deck.json` or built-in |
| 4 | Load labware (Opentrons name, JSON, or grid) | `custom_labware/`, `location_status.yaml`|
| 5 | Drop in vendor driver | `tools/<vendor>_driver.py` |
| 6 | Write thin tool wrapper | `tools/<tool>.py` |
| 7 | Measure XY/Z offset spindle → tool tip | `tools/<tool>_config.yaml` → `offset:`  |
| 8 | Measure Z heights by hand (see §4) | `tools/cnc_config.yaml` → `z_heights:`  |
| 9 | Write the workflow against config + wrapper  | `protocols/<workflow>.py` |
| 10 | Dry-run with `virtual: true`, then hardware  | `tools/cnc_config.yaml` |

---

## See also

- [README — API reference and quickstart](../README.md)
- [examples/hello_cnc/](../examples/hello_cnc/) — minimal motion sanity check
- [examples/liquid_handling/](../examples/liquid_handling/) — full template
- [Opentrons Labware Creator](https://labware.opentrons.com/#/create)
- [Opentrons shared-data labware definitions](https://github.com/Opentrons/opentrons/tree/edge/shared-data/labware/definitions)

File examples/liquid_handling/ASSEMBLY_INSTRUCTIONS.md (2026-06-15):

# Assembly instructions — liquid handling (Sartorius Picus 2)

Full hardware build for the Picus-pipette serial-dilution example.

Source of truth for this BOM is [liquid_handling_CNC_demo_bom.csv](liquid_handling_CNC_demo_bom.csv).

When you're done here, jump back to the [README](README.md) for the software
setup (venv → `pip install` → configure YAML → run).

---

## Purchased parts

| # | Part | Qty | ~Cost (USD) | Link | Notes |
| - | ---- | --: | ---: | ---- | ----- |
| A1 | Genmitsu 3018-PROVer V2 CNC | 1 | 256 | [Amazon](https://www.amazon.ca/Genmitsu-3018-PROVer-Beginner-Emergency-Stop-Spoilboard/dp/B0CMTJ6CZC) | Follow the [SainSmart assembly manual](https://docs.sainsmart.com/article/appuv0ufmb-3018-prover-v-2) up to section 3, skipping steps 2.4 / 2.5 (spindle and acrylic panels). |
| A2 | Sartorius Picus 2 — 5000 µL single-channel pipette | 1 | 1190 | [Sartorius](https://shop.sartorius.com/us/p/picus-2-electronic-single-channel-pipette/LH-747101) | |
| A3 | Sartorius 5000 µL Optifit tips (bag of 100) | 1 | 25.40 | [Sartorius](https://shop.sartorius.com/us/p/optifit-non-sterile-pipette-tips-bulk-in-a-bag-qty-100/Bagged-Pipette-Tip-150mm) | |
| A4 | Opentrons Tough 4-well reservoir (72 mL) | 1 | 6.80 | [Opentrons](https://opentrons.com/products/opentrons-tough-72-ml-4-well-reservoir-25-count) | Sold in a minimum qty of 25. |
| A5 | Corning 24-well plate | 1 | 3.75 | [Corning](https://ecatalog.corning.com/life-sciences/b2c/US/en/Microplates/Assay-Microplates/96-Well-Microplates/Costar%C2%AE-Multiple-Well-Cell-Culture-Plates/p/3738) | Any vendor's 24-well SBS plate should work. Link is min. qty of 100. |
| A7 | M6×10 mm flathead screws | 8 | — | — | For screwing in deck slots. |
| A8 | M5×25 mm panhead screws | 8 | — | — | For Z-offset spacers. |
| A9 | M5 nuts | 8 | — | — | For Z-offset spacers. |
| A10 | Food colouring (water-based) | 1 | — | [Amazon](https://www.amazon.ca/Club-House-Food-Colour-Preparation/dp/B00HVVNFVW) | Any colour. |

## 3D-printed parts

STL + STEP files live in [`cad/`](cad/) (`cad/stl/` to send straight to the
slicer, `cad/step/` to remix in CAD).

| # | Part name | Qty | Notes |
| - | --- | --: | ----- |
| B1 | [`100mm-z-spacer.stl`](cad/stl/100mm-z-spacer.stl) | 2 | Uses M5 hardware to elevate the XZ carriage. |
| B2 | [`deck-slot-5mm-offset.stl`](cad/stl/deck-slot-5mm-offset.stl) | 1 | Installed in deck slot 1. |
| B3 | [`deck-slot-standard.stl`](cad/stl/deck-slot-standard.stl) | 3 | Installed in deck slots 2–4. |
| B4 | [`sartorius-24-tiprack-5000ul.stl`](cad/stl/sartorius-24-tiprack-5000ul.stl) | 2 | Custom 24-tip rack. |
| B5 | [`sartorius-5000ul-pipette-tool-holder-a.stl`](cad/stl/sartorius-5000ul-pipette-tool-holder-a.stl) | 1 | Two-part toolhead mount that clamps around the pipette. |
| B6 | [`sartorius-5000ul-pipette-tool-holder-b.stl`](cad/stl/sartorius-5000ul-pipette-tool-holder-b.stl) | 1 | Two-part toolhead mount that clamps around the pipette. |
| B7 | [`m6-thumb-screw.stl`](cad/stl/m6-thumb-screw.stl) | 8 | For securing labware into deck slots. Any M6 screw works; based on [McMaster 92545A183](https://www.mcmaster.com/92545A183/). |

## Also required

- A computer (Windows / macOS / Linux) with a USB-A port (or the necessary
  dongle) to talk to the CNC over USB serial.
- Tap water for the dilutions.
- Allen keys and screwdrivers.

---

## Assembly

### Stage 1 — Base CNC

Build the Genmitsu 3018 per the [SainSmart manual](https://docs.sainsmart.com/article/appuv0ufmb-3018-prover-v-2)
up to section 3, **skipping steps 2.4 (spindle) and 2.5 (acrylic panels)** —
they aren't needed for this build.

Confirm homing works in [Candle](https://docs.sainsmart.com/article/bj9o96wcbc-how-to-set-up-use-candle-for-multiple-operations)
or another GRBL UI before the Python library ever touches it.

### Stage 2 — Elevate the gantry and mount the deck

1. Install the two `100mm-z-spacer.stl` parts (B1) between the XZ carriage and
   the gantry uprights using M5×25 panhead screws + M5 nuts (A8, A9). This
   gives the Picus tip clearance over the deck.
2. Bolt the four deck slot plates (B2 ×1 in slot 1, B3 ×3 in slots 2–4) onto
   the CNC bed with M6×10 flatheads (A7). Square them against the X / Y axes
   before final torque — once squared, slot positions are fixed.

### Stage 3 — Mount the Picus pipette

1. Clamp the two-part pipette holder (B5 + B6) around the Picus body.
2. Bolt the assembly onto the spindle carriage in place of the stock spindle.
   The tip should hang below the gantry far enough to reach the deepest well
   with a few mm of clearance.
3. Plug the Picus USB cable into the host PC. Note the COM port name and set
   it in [`tools/picus_config.yaml`](tools/picus_config.yaml).

### Stage 4 — Calibrate

Measure aspirate / dispense / tip-pickup / tip-eject Z heights by hand:
jog Z with a GRBL UI (e.g. [Candle](https://docs.sainsmart.com/article/bj9o96wcbc-how-to-set-up-use-candle-for-multiple-operations))
until the tip kisses the target surface, then write the numbers into
[`tools/cnc_config.yaml`](tools/cnc_config.yaml) under `z_heights:`. See
[docs/SETUP.md §4](../../docs/SETUP.md#4-calibrate-z-heights) for the
rationale and the recommended labels.

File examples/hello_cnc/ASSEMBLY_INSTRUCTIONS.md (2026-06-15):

# Assembly instructions — hello_cnc

Minimum physical setup for verifying the CNC and its USB serial connection.
This is what every example builds on top of.

**Target time:** ~1 hour, once parts are in hand.

Source of truth for this BOM is [hello_CNC_bom.csv](hello_CNC_bom.csv).

---

## Purchased parts

| # | Part | Qty | ~Cost (USD) | Link | Notes |
| - | ---- | --- | --- | ---- | ----- |
| A1 | Genmitsu 3018-PROVer V2 CNC | 1 | 256 | [Amazon](https://www.amazon.ca/Genmitsu-3018-PROVer-Beginner-Emergency-Stop-Spoilboard/dp/B0CMTJ6CZC) | Follow the [SainSmart assembly manual](https://docs.sainsmart.com/article/appuv0ufmb-3018-prover-v-2) up to section 3, **skipping steps 2.4 / 2.5** (spindle and acrylic panels — not needed). |

## Also required

- A computer (Windows / macOS / Linux) with a USB-A port (or the necessary
  dongle) to talk to the CNC over USB serial.

---

## Assembly

1. Build the CNC per the SainSmart manual through section 3, skipping the
   spindle install (2.4) and acrylic side panels (2.5).
2. Plug the controller into the host PC via the included USB-A → USB-B cable.
3. Run the [hello_cnc.py](hello_cnc.py) script from the [README](README.md) to
   verify homing, jogging, and the spindle output (M3 / M5) all respond.

If the smoke test passes, you're done — move on to one of the tool-equipped
examples (liquid handling, vacuum pick-and-place, …).

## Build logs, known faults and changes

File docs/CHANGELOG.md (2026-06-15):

# Changelog

## Unreleased
- **Repo housekeeping**: `CHANGELOG.md`, `README_PYPI.md`, and `LICENSE` moved into [`docs/`](.) so the top-level tree only carries the GitHub-landing `README.md` and source dirs. `pyproject.toml` `readme = "docs/README_PYPI.md"`, `license-files = ["docs/LICENSE"]`, and the `Changelog` URL were updated; root README's license link likewise. [`examples/AGENTS.md`](../examples/AGENTS.md) stays under `examples/` so Copilot/Codex/Cursor auto-discover the scaffolding conventions from inside an example folder.
- **Pick-and-place: storage + gameboard 3D-printed racks added.** New parts `storage-15-tuberack-100ul.{step,stl}` (deck slot 3, back-left, X/O reservoir) and `gameboard-15-tuberack-100ul.{step,stl}` (deck slot 4, back-right, 3\u00d73 play area) shipped under [`examples/vacuum_pick_and_place/cad/`](../examples/vacuum_pick_and_place/cad/). Filenames mirror the matching Opentrons `loadName`s (`storage_15_tuberack_100ul.json`, `gameboard_15_tuberack_100ul.json`) so JSON \u2194 CAD pairing is obvious. BOM (rows B6/B7) + ASSEMBLY_INSTRUCTIONS Stage 2 wording + README deck-layout table all updated to reflect slots 3/4 (matching what `tools/cnc_config.yaml` already declared \u2014 the README was the stale doc).
- **CAD filenames normalized to kebab-case.** Renamed `M6_thumb_screw` \u2192 `m6-thumb-screw`, `suction_cup_holder` \u2192 `suction-cup-holder`, `sartorius_24_tiprack_5000ul` \u2192 `sartorius-24-tiprack-5000ul`, and `sartorius-5000uL-pipette-tool-holder-{A,B}` \u2192 `sartorius-5000ul-pipette-tool-holder-{a,b}` so every STL/STEP file follows the same lowercase-kebab convention. References in [`liquid_handling/ASSEMBLY_INSTRUCTIONS.md`](examples/liquid_handling/ASSEMBLY_INSTRUCTIONS.md), [`vacuum_pick_and_place/ASSEMBLY_INSTRUCTIONS.md`](examples/vacuum_pick_and_place/ASSEMBLY_INSTRUCTIONS.md), and both BOM CSVs updated to match. The Opentrons labware load name `sartorius_24_tiprack_5000ul` (in `custom_labware/*.json`, `cnc_config.yaml`, `deck_preset.yaml`) stays snake_case \u2014 that's the Opentrons load-name convention and must match the JSON filename for `load_definition()` to resolve.
- **CAD files moved per-example.** The top-level `3d printing files/` dump is gone; each example now ships its 3D-printed parts in its own `cad/{step,stl}/` folder.
  - [`examples/liquid_handling/cad/`](examples/liquid_handling/cad/): `100mm-z-spacer`, `deck-slot-5mm-offset`, `deck-slot-standard`, `m6-thumb-screw`, `sartorius-24-tiprack-5000ul`, `sartorius-5000ul-pipette-tool-holder-a`, `sartorius-5000ul-pipette-tool-holder-b`.
  - [`examples/vacuum_pick_and_place/cad/`](examples/vacuum_pick_and_place/cad/): `deck-slot-standard`, `m6-thumb-screw`, `suction-cup-holder`, `vacuum-gripper-toolhead-mount`, `vacuum-pump-mounting-plate`.
  - Shared parts (`deck-slot-standard`, `m6-thumb-screw`) are duplicated under each example so each one is a self-contained build (\u003c1 MB extra total).
- **Assembly typo fixes.** `deck-slot-5mm-taller.stl` \u2192 `deck-slot-5mm-offset.stl`, `M6-thumb-screws.stl` \u2192 `m6-thumb-screw.stl`, `suction-cup-holder.stl` (was unchanged but linked) in the two `ASSEMBLY_INSTRUCTIONS.md` and BOM CSVs. Every print-row in the BOM is now a clickable link to its `cad/stl/` file.

## 0.9.1 - 2026-06-15
- **Separate PyPI README.** `pyproject.toml` now points `readme` at a new `README_PYPI.md` — a slim, text-only API summary (`CNC_Machine`, `Deck`, `DeckState`, minimal `cnc_config.yaml`) with a link out to the full GitHub README for hardware/build docs and example projects. The GitHub `README.md` stays as the rich landing page (hero gifs, reference applications, full API reference).

## 0.9.0 - 2026-06-15
- **COM-port discovery docs.** Finding the GRBL board's serial port is not self-discoverable, so [docs/SETUP.md §0](docs/SETUP.md#finding-the-serial-port-windows--macos--linux) now has a *Finding the serial port (Windows / macOS / Linux)* subsection: a table mapping each example to the exact `cnc_config.yaml` (and `picus_config.yaml` for liquid_handling) that needs editing, the unplug/list/plug-in identification trick, and per-OS commands (`Get-CimInstance Win32_SerialPort`, `ls /dev/tty.*`, `ls /dev/ttyUSB* /dev/ttyACM*`) plus CH340 driver / `dialout` group notes. Each example README and the root README's Quick start now link to it inline.
- **README hero**: added side-by-side preview gifs (5\u00d7 speed) at the top of the README for the liquid-handling and pick-and-place examples; each gif links out to the full-length YouTube recording. Renamed the *Reference applications* table column from `Photos / videos` to `Sample workflow video` and linked the same YouTube videos there (`hello_cnc` left blank). Source `media/*.mp4` recordings are too large for git and are hosted on YouTube; `media/*.mp4`/`*.mov`/`*.webm` are now gitignored, only the preview gifs are tracked.
- **Breaking: `Deck(deck_definition)` is now required \u2014 no default.** Previously `Deck()` silently picked `cnc_4_slot_deck`. Callers must now pass the deck name explicitly (`Deck("cnc_4_slot_deck")` for the Genmitsu 3018 layout, `Deck("cnc_1_slot_deck")` for the open layout, or a path to a custom JSON) so the CNC footprint is visible at the call site. Updated `examples/vacuum_pick_and_place/app_runtime.py`, README, and [docs/SETUP.md](docs/SETUP.md).- **Clarified that the built-in `cnc_4_slot_deck` is sized for the Genmitsu 3018-PROVer V2** (~300×180 mm bed). Larger CNCs (3040, 6040, …) should copy the JSON and remeasure slot corners. Note added to README, [docs/SETUP.md](docs/SETUP.md), [examples/AGENTS.md](examples/AGENTS.md), the `Deck` docstring, and both example `cnc_config.yaml` files.
- **Per-example `z_helper.py` removed.** Each example's shipped `z_heights:` is calibrated for the reference build in its `ASSEMBLY_INSTRUCTIONS.md`; if a downstream build differs, remeasure by hand (jog with [Candle](https://docs.sainsmart.com/article/bj9o96wcbc-how-to-set-up-use-candle-for-multiple-operations) or `cnc.move_to_point(...)` from a Python REPL) and edit the `z_heights:` block. Procedure documented in [docs/SETUP.md §4](docs/SETUP.md#4-calibrate-z-heights).
- **Smoke-test step dropped from per-example READMEs.** `hello_cnc/hello_cnc.py` is a one-time CNC sanity check for new hardware, not a prerequisite for every protocol. The standard user journey in [examples/README.md](examples/README.md) is now 3 steps (hardware → software → configure & run).
- Updated [examples/AGENTS.md](examples/AGENTS.md) (dropped §6 z_helper.py section, README guidance) and top-level [README.md](README.md) (Quick start, Z calibration section) to match.
- **BOM tables populated** in each example's `ASSEMBLY_INSTRUCTIONS.md`. Each example gets a sibling `<project>_bom.csv` (`hello_CNC_bom.csv`, `liquid_handling_CNC_demo_bom.csv`, `pick_and_place_CNC_demo_bom.csv` — matching the `Project` field in the upstream spreadsheet) so the parts list is diffable and renders directly on GitHub. The upstream master spreadsheet is kept locally only and is gitignored.
- New `examples/hello_cnc/ASSEMBLY_INSTRUCTIONS.md` covering the base-CNC build (the smoke test had no assembly doc before).
- **License changed from MIT to GPL-3.0-or-later.** Updated `LICENSE` to the full GNU GPL v3 text and `pyproject.toml`'s `license` field accordingly.
- **README restructured** around the 3-step workflow (Mount a Tool → Define the Deck → Write a Workflow). Trimmed redundancy: removed the long "Starting a New Application" section (now covered by [docs/SETUP.md](docs/SETUP.md) and the per-example READMEs). Moved authors and acknowledgements to the bottom. Added an acknowledgement to the [KABLab](https://sites.bu.edu/kablab/) at Boston University with a citation to *List et al., "ASMI: An automated, low-cost indenter for soft matter", HardwareX 20, e00601 (2024)*.
- **Z calibration helper docs**: the helper is shipped per-example (`examples/<name>/z_helper.py`) — README and `docs/SETUP.md` now link to both shipped variants instead of only the liquid_handling one.
- **Repo cleanup**:
  - Removed `tests/` — the only test file was broken (wrong import path, stale bounds assertions) and `examples/hello_cnc/hello_cnc.py` is the de-facto hardware smoke test.
  - Removed local build artifacts from the working tree (`dist/`, `.pytest_cache/`, `__pycache__/`, `src/cnc_4_science.egg-info/`); added `.pytest_cache/` to `.gitignore`.
- **Hardware docs (placeholders)**: each example now ships a self-contained `ASSEMBLY_INSTRUCTIONS.md` next to its README (BOM, base CNC + deck stages, per-tool wiring, CAD index). Targets a ~1-hour build once parts are in hand.
- **README structure standardized** across examples: every example README now follows the same 5-step user journey — hardware setup (link to `ASSEMBLY_INSTRUCTIONS.md`) → software setup (venv + `pip install`) → smoke test (`hello_cnc`) → calibrate Z → run protocol. New top-level `examples/README.md` summarizes the journey and indexes every example. The root README adds a quick-start block and a media-placeholder table for per-example photos/videos.
- **Examples scaffolding guide**: new [`examples/AGENTS.md`](examples/AGENTS.md) documenting the shared layout, config schema, and driver-class pattern for new examples.
- **New example**: `examples/vacuum_pick_and_place/` — physical tic-tac-toe over a CNC gantry with a vacuum gripper. Supports 1-player vs Easy/Medium/Hard AI and 2-player modes; pieces are picked from a 15-well storage rack and placed on a 15-well game board (3x3 play area). Adapted from `kelvinchow23/cnc-tictactoe` without SiLA. Follows the `liquid_handling/` template: `tools/cnc_config.yaml` + `tools/vacuum_config.yaml`, `tools/vacuum_gripper.py` (thin wrapper that drives the CNC's spindle output via `cnc.spindle_on()` / `cnc.spindle_off()` instead of a separate serial port — the vacuum pump is wired to the GRBL spindle terminals), `protocols/tic_tac_toe.py` CLI entry point, custom labware in `custom_labware/`, deck preset in `presets/`.
  - **Shared `GameSession`** (`game_session.py`): single thread-safe state machine that owns the board, deck state, hardware handles, and AI. The CLI and the optional web frontend both drive the same `GameSession`, so behaviour is identical across surfaces. `app_runtime.py` factors out CNC/gripper bootstrap and shutdown.
  - **Optional lightweight web frontend** (`web/app.py` + `web/static/`): FastAPI app exposing `/api/state`, `/api/start`, `/api/move`, `/api/ai-move`, `/api/reset`, with a vanilla HTML/JS single-page UI. The board flashes the next CNC move before the gantry executes it (peek/play split). 1-/2-Player mode selector greys out AI difficulty and symbol-selection in 2-player mode. Reset replays the move history in reverse to clear the board. Run with `uvicorn web.app:app --host 0.0.0.0 --port 8000`. The CLI still works exactly as before — `python protocols/tic_tac_toe.py`.

## 0.8.1 - 2026-06-11
- **Docs**: added [`docs/SETUP.md`](docs/SETUP.md) — end-to-end walkthrough for new applications (deck definition → labware sourcing options → toolhead driver/wrapper → XY/Z offset measurement → Z calibration → protocol → dry-run). Linked from README quickstart.
  - Prerequisites now explicitly call out that `bounds:` is CNC-model-specific (shipped configs target the Genmitsu 3018) and recommend verifying real travel with a GRBL UI like [Candle](https://docs.sainsmart.com/article/bj9o96wcbc-how-to-set-up-use-candle-for-multiple-operations) before editing `cnc_config.yaml`.
  - Reworded the Z-from-labware-is-ignored rationale: too many independently-variable terms (deck shim, labware seating, tool mount, tip length) to maintain four agreeing calibrations, so we collapse to one empirical Z per (tool, labware, action) via `z_helper.py`.

## 0.8.0 - 2026-06-10
- **Deck definitions renamed and addressable by name**:
  - `deck/cnc_deck_definition.json` → `deck/cnc_4_slot_deck.json` (deckId `cnc_4_slot_deck`).
  - `deck/cnc_open.json` → `deck/cnc_1_slot_deck.json` (deckId `cnc_1_slot_deck`).
  - `Deck(deck_definition)` now accepts a built-in name (`Deck("cnc_1_slot_deck")`) or a path. Default is unchanged (`cnc_4_slot_deck`).
  - Example `tools/cnc_config.yaml` declares `deck.definition: cnc_4_slot_deck` so the deck choice is visible from config.
- **Examples reorganized**: merged `templates/` and `examples/` into a single `examples/` tree. Removed legacy `liquid_handling_demo/`. `examples/startup/` renamed to `examples/hello_cnc/`.
- **Liquid handling demo restructured** as a reusable template at `examples/liquid_handling/`:
  - Protocol moved to `protocols/serial_dilution_demo.py` (was `protocol.py` at root).
  - Per-tool config split: CNC is now treated as just another tool. Configs live under `tools/`:
    - `tools/cnc_config.yaml` — CNC machine, deck layout (slot→role), Z heights, virtual flag.
    - `tools/picus_config.yaml` — pipette tool (port, offset, default_speed, volumes). Replaces the old `tool_definitions.json`.
  - Consistent `picus_*` naming throughout: `tools/picus_pipette.py` (`PicusPipette` wrapper, was `SartoriusPipette`) and `tools/picus_driver.py` (vendored Picus 2 driver, was the `picus/` subpackage).
  - Deck slot assignment moved into `cnc_config.yaml` under `deck:` so it's visible from config instead of buried in the protocol.
- **New `CNC_Machine.from_config(path)` classmethod**: loads CNC port, baud, and bounds from a YAML config file. Accepts `**overrides` kwargs.
- `hardware_check.py` and `z_helper.py` updated to use `CNC_Machine.from_config(...)` and the new per-tool config paths.
- Z bounds in `z_helper.py` now derive from CNC config (`cnc.Z_LOW_BOUND` / `cnc.Z_HIGH_BOUND`) instead of hardcoded `-35..0`.

## 0.7.0 - 2026-06-09
- **Distribution renamed**: PyPI package is now `cnc-4-science` (was `cnc-machine-core`). Import name `cnc_machine_core` is unchanged.
- **Published to PyPI**: install with `pip install cnc-4-science`. Releases are automated via GitHub Actions on `v*` tags using PyPI Trusted Publisher (OIDC).
- **Liquid handling demo moved** from `liquid_handling_demo/serial_dilution/` (installable package) to `templates/serial_dilution_demo/` (flat-layout reference template). Run with `python protocol.py`; no install of the demo itself required.
- Added project metadata (license, authors, urls, classifiers, keywords) to `pyproject.toml`.
- Added `.github/workflows/publish.yml` for automated PyPI releases.
- Removed redundant top-level `requirements.txt` (dependencies now in `pyproject.toml`).
- Templates directory is excluded from the published wheel (only library code ships to PyPI).
- Synced `pyproject.toml` version to changelog (was stale at 0.1.0).

## 0.6.0 - 2026-06-09
- Restructured liquid handling demo as installable package `serial-dilution-demo` under `liquid_handling_demo/serial_dilution/`.
- Package layout: `src/serial_dilution_demo/` with `tools/` (incl. vendored picus driver) and `protocol.py` entry point.
- `pyproject.toml` declares `cnc-machine-core` as a local path dependency (uv editable) — no `sys.path` hacks.
- Entry point: `serial-dilution` CLI command (or `python -m serial_dilution_demo`).
- Standard labware loaded at runtime via `opentrons-shared-data`; only custom tip rack JSON stored locally.
- Added `Deck.load_labware_definition(slot_id, dict)` to `cnc_machine_core`.
- Added `opentrons-shared-data` to `cnc-machine-core` dependencies.

## 0.5.0 - 2026-03-18
- Restructured to standard `src/` layout: core modules now under `src/cnc_machine_core/`.
- Package imports changed: `from cnc_machine_core import CNC_Machine, Deck, DeckState`.
- Deck and labware JSON data files moved into the package.

## 0.4.1 - 2026-03-18
- Added `is_alarm()` method to check if GRBL is in alarm state.
- Added `recover_if_alarm()` method that auto-homes on alarm before moves.
- All move methods now call `recover_if_alarm()` before executing.
- `wait_until_idle()` now raises `RuntimeError` immediately on alarm instead of timing out after 60s.

## 0.4.0 - 2026-03-18
- Moved `DeckState` well status tracker to core as `deck_state` module.
- Removed app-specific `VALID_STATUSES` — statuses are now application-defined strings.
- Added `deck_state` to `pyproject.toml` exports.
- Added sample deck preset template at `templates/starter_app/presets/deck_preset.yaml`.
- Updated README with DeckState API docs and architecture diagram.

## 0.3.0 - 2026-03-18
- Redesigned `cnc_deck` module with `Well`, `Labware`, and `Deck` object model (Opentrons-inspired).
- `load_labware()` now returns a `Labware` object; wells accessed via `plate["A1"].position(offset=...)`.
- Old tuple-based convenience methods (`list_wells`, `get_well_position`) still work for backward compatibility.
- Added `deck/cnc_open.json` — single-slot open deck layout (no labware required).
- Updated starter template protocols to use new Well/Labware API.

## 0.2.0 - 2026-03-18
- Added `cnc_deck` module with standard `Deck` class for slot lookup, labware loading, well coordinate resolution, and well ordering.
- Added standard 4-slot deck definition at `deck/cnc_deck_definition.json`.
- Added starter application template at `templates/starter_app/` with sample tool, vacuum gripper template, tool definitions template, simple well-cycle protocol, and Z calibration helper.
- Updated `pyproject.toml` to export `cnc_deck` module and include deck/labware data files.
- Updated README with deck/labware API docs, "Starting a New Application" guide, architecture diagram, and tool contract specification.

## 0.1.3 - 2026-03-17
- Added `xyxy` and `yxyx` axis orders to `move_to_point_safe_orthogonal()` accepting dual waypoints for 4-step routing.
- Fixed `wait_until_idle()` serial buffer flush to avoid reading stale `ok` responses.

## 0.1.2 - 2026-03-13
- Added `move_to_point_safe_orthogonal()` method for axis-separated safe moves through a waypoint (Y->X->Y or X->Y->X).

## 0.1.1 - 2026-03-11
- Added `spindle_on(speed)` and `spindle_off()` methods using GRBL M3/M5 spindle commands.

## 0.1.0 - 2026-03-11
- Added `pyproject.toml` so `cnc_machine.py` can be installed as package `cnc-machine-core`.
- Declared runtime dependencies (`pyyaml`, `pyserial`) for clean installs.

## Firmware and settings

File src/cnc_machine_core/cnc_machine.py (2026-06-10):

import logging
import serial
import time
import yaml


class CNC_Machine:
    """
    GRBL CNC controller helper with:
      - Persistent serial connection
      - Virtual (no-COM) mode for testing
      - Structured logging (DEBUG/INFO/WARNING/ERROR)
    """

    def __init__(
        self,
        com,
        baud_rate=115200,
        x_low_bound=0,
        x_high_bound=280,
        y_low_bound=0,
        y_high_bound=180,
        z_low_bound=-37,
        z_high_bound=0,
        virtual=False,
        locations_file=None,
        log_level=logging.INFO,
    ):
        self.logger = logging.getLogger(__name__ + ".CNC_Machine")
        if not self.logger.handlers:
            h = logging.StreamHandler()
            fmt = logging.Formatter(
                "%(asctime)s | %(levelname)s | %(name)s | %(message)s",
                datefmt="%H:%M:%S",
            )
            h.setFormatter(fmt)
            self.logger.addHandler(h)
        self.logger.setLevel(log_level)

        # Set constants from parameters
        self.BAUD_RATE = baud_rate
        self.X_LOW_BOUND = x_low_bound
        self.X_HIGH_BOUND = x_high_bound
        self.Y_LOW_BOUND = y_low_bound
        self.Y_HIGH_BOUND = y_high_bound
        self.Z_LOW_BOUND = z_low_bound
        self.Z_HIGH_BOUND = z_high_bound

        self.VIRTUAL = virtual
        self.SERIAL_PORT = com
        self.ser = None
        self.LOCATIONS = self.load_from_yaml(locations_file)

        self._virtual_log = []
        self._virtual_state = "Idle"
        self._virtual_pos = {"X": 0.0, "Y": 0.0, "Z": 0.0}

        self.logger.info(
            "CNC_Machine initialized (virtual=%s, port=%s, baud=%s)",
            self.VIRTUAL,
            self.SERIAL_PORT,
            self.BAUD_RATE,
        )

    def load_from_yaml(self, file_in):
        if not file_in:
            self.logger.warning("No locations_file provided; LOCATIONS will be empty.")
            return {}
        try:
            with open(file_in, "r") as f:
                data = yaml.safe_load(f) or {}
            self.logger.info("Loaded locations from %s", file_in)
            return data
        except FileNotFoundError:
            self.logger.error("locations_file %s not found; LOCATIONS empty.", file_in)
            return {}
        except Exception as e:
            self.logger.exception("Failed to load YAML '%s': %s", file_in, e)
            return {}

    @classmethod
    def from_config(cls, config_path, **overrides):
        """Construct a CNC_Machine from a YAML config file.

        Expected schema (all fields optional except cnc.com_port):
            cnc:
              com_port: COM4
              baud_rate: 115200
              bounds:
                x: [0, 280]
                y: [0, 180]
                z: [-37, 0]
            virtual: false
            locations_file: location_status.yaml

        Extra kwargs override values from the file.
        """
        with open(config_path, "r", encoding="utf-8") as f:
            cfg = yaml.safe_load(f) or {}
        cnc_cfg = cfg.get("cnc", {})
        bounds = cnc_cfg.get("bounds", {})
        x_lo, x_hi = bounds.get("x", [0, 280])
        y_lo, y_hi = bounds.get("y", [0, 180])
        z_lo, z_hi = bounds.get("z", [-37, 0])
        kwargs = {
            "com": cnc_cfg.get("com_port"),
            "baud_rate": cnc_cfg.get("baud_rate", 115200),
            "x_low_bound": x_lo,
            "x_high_bound": x_hi,
            "y_low_bound": y_lo,
            "y_high_bound": y_hi,
            "z_low_bound": z_lo,
            "z_high_bound": z_hi,
            "virtual": cfg.get("virtual", False),
            "locations_file": cfg.get("locations_file"),
        }
        kwargs.update(overrides)
        return cls(**kwargs)

    def connect(self):
        if self.VIRTUAL:
            self.logger.info("[VIRTUAL] connect() noop.")
            return
        if self.ser and self.ser.is_open:
            self.logger.debug("Serial already open on %s", self.SERIAL_PORT)
            return
        self.logger.info(
            "Opening serial port %s @ %s baud", self.SERIAL_PORT, self.BAUD_RATE
        )
        self.ser = serial.Serial(self.SERIAL_PORT, self.BAUD_RATE)
        self.wake_up()

    def close(self):
        if self.VIRTUAL:
            self.logger.info("[VIRTUAL] close() noop.")
            return
        if self.ser:
            try:
                self.logger.info("Closing serial port.")
                self.ser.close()
            finally:
                self.ser = None

    def _ensure_connected(self):
        if self.VIRTUAL:
            return
        if not self.ser or not self.ser.is_open:
            self.connect()

    def wake_up(self):
        if self.VIRTUAL:
            self.logger.debug("[VIRTUAL] wake_up() noop.")
            return
        self._ensure_connected()
        self.logger.debug("Waking GRBL and clearing greeting.")
        self.ser.reset_input_buffer()
        self.ser.write(b"\r\n\r\n")
        time.sleep(2.0)
        self.ser.reset_input_buffer()

    def _readline(self, timeout=2.0):
        if self.VIRTUAL:
            return ""
        self._ensure_connected()
        self.ser.timeout = timeout
        line = self.ser.readline()
        s = line.decode("utf-8", errors="ignore").strip()
        if s:
            self.logger.debug("<< %s", s)
        return s

    def _query_status(self):
        if self.VIRTUAL:
            s = f"<{self._virtual_state}|MPos:{self._virtual_pos['X']:.3f},{self._virtual_pos['Y']:.3f},{self._virtual_pos['Z']:.3f}|FS:0,0>"
            self.logger.debug("[VIRTUAL] ? => %s", s)
            return s
        self._ensure_connected()
        self.ser.write(b"?")
        self.logger.debug(">> ?")
        return self._readline(timeout=0.5)

    def is_alarm(self):
        """Query GRBL status and return True if machine is in alarm state."""
        if self.VIRTUAL:
            return False
        self._ensure_connected()
        status = self._query_status()
        return "<Alarm" in status or "ALARM" in status

    def recover_if_alarm(self):
        """Check for alarm state and home to recover if needed."""
        if self.is_alarm():
            self.logger.warning("Alarm detected — homing to recover.")
            self.home()
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

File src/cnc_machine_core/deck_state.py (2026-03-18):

"""YAML-backed well status tracker for CNC deck slots.

Tracks per-well status strings across all deck slots. Statuses are
application-defined — the tracker itself is generic.

Usage:
    from deck_state import DeckState

    ds = DeckState()
    ds.init_wells_from_labware("1", plate)          # from Labware or raw dict
    ds.init_from_preset({"1": {"A1": "empty"}})     # from preset dict
    ds.set_status("1", "A1", "sample")              # update (auto-saves)
    loc = ds.find_next(["1", "2"], "empty")          # find first match
"""

import yaml
from pathlib import Path


class DeckState:
    """YAML-backed well status tracker for all deck slots."""

    def __init__(self, state_file=None):
        self.state_file = Path(state_file) if state_file else None
        self.slots = {}  # {slot_id: {well_name: status}}

    # --- Persistence ---

    def save(self, path=None):
        path = Path(path) if path else self.state_file
        if path is None:
            raise ValueError("No path specified for save")
        path.parent.mkdir(parents=True, exist_ok=True)
        with path.open("w", encoding="utf-8") as f:
            yaml.dump(self.slots, f, default_flow_style=False)
        self.state_file = path

    def load(self, path=None):
        path = Path(path) if path else self.state_file
        if path is None:
            raise ValueError("No path specified for load")
        with path.open("r", encoding="utf-8") as f:
            self.slots = yaml.safe_load(f) or {}
        self.state_file = path

    @classmethod
    def from_file(cls, path):
        ds = cls(state_file=path)
        ds.load()
        return ds

    # --- Preset configuration ---

    def init_from_preset(self, preset):
        """Populate state from a preset dict.

        Args:
            preset: Dict mapping slot_id -> list of (well_name, status) or
                    slot_id -> {well_name: status}.
        """
        for slot_id, wells in preset.items():
            slot_key = str(slot_id)
            if slot_key not in self.slots:
                self.slots[slot_key] = {}
            if isinstance(wells, dict):
                for well, status in wells.items():
                    self.slots[slot_key][well] = status
            else:
                for well, status in wells:
                    self.slots[slot_key][well] = status

    def init_wells_from_labware(self, slot_id, labware_data,
                                default_status="empty"):
        """Initialize all wells in a slot from labware ordering.

        Args:
            labware_data: Either a raw labware dict (with "ordering" key)
                or a cnc_deck.Labware object (with .well_names() method).
        """
        slot_key = str(slot_id)
        if slot_key not in self.slots:
            self.slots[slot_key] = {}
        if hasattr(labware_data, "well_names"):
            well_list = labware_data.well_names()
        else:
            ordering = labware_data.get("ordering", [])
            well_list = [well for col in ordering for well in col]
        for well in well_list:
            if well not in self.slots[slot_key]:
                self.slots[slot_key][well] = default_status

    # --- Accessors ---

    def set_status(self, slot_id, well_name, status):
        slot_key = str(slot_id)
        if slot_key not in self.slots:
            self.slots[slot_key] = {}
        self.slots[slot_key][well_name] = status
        if self.state_file:
            self.save()

    def get_status(self, slot_id, well_name):
        return self.slots.get(str(slot_id), {}).get(well_name, "empty")

    def find_next(self, slot_ids, status, ordering_map=None):
        """Find the first well matching status across given slots.

        Iterates column-first using labware ordering if provided,
        otherwise dict insertion order.

        Args:
            slot_ids: List of slot IDs to search.
            status: Target well status to match.
            ordering_map: Optional dict mapping slot_id to
                labware ordering lists.

        Returns:
            (slot_id, well_name) or None.
        """
        for sid in slot_ids:
            slot_key = str(sid)
            wells = self.slots.get(slot_key, {})
            if ordering_map and slot_key in ordering_map:
                ordered = [
                    w for col in ordering_map[slot_key] for w in col
                ]
            else:
                ordered = list(wells.keys())
            for well in ordered:
                if wells.get(well) == status:
                    return (slot_key, well)
        return None

    def count(self, slot_ids, status):
        """Count wells with a given status across slots."""
        total = 0
        for sid in slot_ids:
            wells = self.slots.get(str(sid), {})
            total += sum(1 for s in wells.values() if s == status)
        return total

    def summary(self):
        """Print a compact summary of all slot states."""
        for slot_id in sorted(self.slots):
            wells = self.slots[slot_id]
            counts = {}
            for status in wells.values():
                counts[status] = counts.get(status, 0) + 1
            parts = [f"{s}={n}" for s, n in sorted(counts.items())]
            print(f"  Slot {slot_id}: {', '.join(parts)}")

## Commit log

2026-03-10 Added sample labware following opentrons format
    - custom labware generated using opentrons labware creator gui. add stl/native CAD file (should also include image)
    -axygen labware pulled from opentrons as a reference
    [vialtrayholder_25_tuberack_1000ul.f3d, vialtrayholder_25_tuberack_1000ul.stl]
2026-03-10 Remove FractionCollector class and associated tools from fraction_collector.py
    [vialtrayholder_25_tuberack_1000ul.f3d, vialtrayholder_25_tuberack_1000ul.stl]
2026-03-11 Add spindle control methods and update documentation
    - Implemented `spindle_on(speed)` and `spindle_off()` methods in `cnc_machine.py` for spindle control.
    - Created `CHANGELOG.md` to document version updates and added runtime dependencies.
2026-03-18 Restructure to src/cnc_machine_core layout, add alarm recovery, update README
    [vialtrayholder_25_tuberack_1000ul.f3d, vialtrayholder_25_tuberack_1000ul.stl]
2026-03-18 Fix home() to send unlock separately so it works from alarm state
    [cnc_machine.py]
2026-06-09 feat: rename to cnc-4-science, restructure demo as flat template (#10)
    * Add liquid handling demo with serial dilution protocol and z calibration helper
    * Add .venv to gitignore, untrack serial_dilution venv
    * feat: rename to cnc-4-science, restructure demo as flat template
    - pyproject: rename dist cnc-machine-core -> cnc-4-science (import
    name cnc_machine_core unchanged); bump to 0.7.0; add author,
    license, urls, classifiers, keywords metadata
    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
2026-06-11 docs: add docs/SETUP.md walkthrough; clarify CNC bounds and Z calibration rationale
    - New docs/SETUP.md: end-to-end how-to (deck -> labware sourcing options -> toolhead driver/wrapper -> XY/Z offset measurement -> Z calibration -> protocol -> dry-run). Linked from README quickstart.
    - Call out that bounds: in cnc_config.yaml is CNC-model-specific (shipped configs target the Genmitsu 3018) and recommend verifying real travel with a GRBL UI (Candle/UGS/bCNC) before editing.
    - Reword Z-from-labware-is-ignored rationale: too many independently-variable terms (deck shim, labware seating, tool mount, tip length) to keep 4 calibrations agreeing, so collapse to one empirical 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
2026-06-11 examples: add vacuum_pick_and_place tic-tac-toe demo (no SiLA, CLI only)
    New examples/vacuum_pick_and_place/ adapted from kelvinchow23/cnc-tictactoe.
    Follows the liquid_handling/ template:
    - tools/cnc_config.yaml + tools/vacuum_config.yaml split (CNC owns deck/Z,
    tool owns RPM/delays).
    - tools/vacuum_gripper.py: thin wrapper that drives the CNC's spindle output
    (M3/M5) instead of a separate serial port. The vacuum pump is wired to the
    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
2026-06-11 feat: add lightweight FastAPI web frontend for vacuum_pick_and_place
    - Extract GameSession (game_session.py): single thread-safe state machine
    that owns the board, deck state, move history, AI, and hardware handles.
    AI auto-plays inside make_move() so callers never need to drive an
    intermediate AI turn.
    - app_runtime.py: shared bootstrap (load_configs, build_session, shutdown)
    used by both the CLI and the web app.
    - web/app.py: ~80-line FastAPI app exposing /api/state, /api/start,
    /api/move, /api/reset. Sync request model (CNC moves block; no need for
    WebSockets). Maps ValueError -> 400, RuntimeError -> 409.
    - web/static/{index.html,game.js,style.css}: vanilla single-page UI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
2026-06-14 refactor: repo cleanup + hardware-docs placeholders + UI polish
    - Remove broken tests/ (stale imports + bounds); hello_cnc/hello_cnc.py is the smoke test.
    - Add docs/hardware/{README,BOM,ASSEMBLY,CAD}.md placeholders for the upcoming hardware-build docs.
    - Add examples/README.md (index) and examples/AGENTS.md (scaffolding guide for new examples).
    - vacuum_pick_and_place: AI peek/play split (board flashes next CNC move before gantry executes), 1-/2-Player labels with greyed-out controls in 2-player, 'O goes first' note, huge centered board, AC logo header, collapsed debug bar, reset replays move history in reverse.
    - Add .pytest_cache/ to .gitignore.
    [cnc_config.yaml]
2026-06-14 docs: split hardware docs - base platform in docs/hardware/, per-tool in each example
    - docs/hardware/ now covers only the shared base CNC + deck.
    - Per-tool BOM/assembly/CAD moved into examples/<name>/HARDWARE.md.
    - Cross-linked from each example README and the root README.
2026-06-14 docs: standardize user journey across examples; rename HARDWARE.md -> ASSEMBLY_INSTRUCTIONS.md
    - Each example README now follows the same 5-step flow: hardware (link to ASSEMBLY_INSTRUCTIONS.md, ~1 hr) -> venv + pip install -> configure YAML -> hello_cnc smoke test -> calibrate Z -> run protocol.
    - Hello CNC README expanded with venv + pip install + config steps so it is a complete smoke-test recipe.
    - examples/README.md adds the standard journey + indexes ASSEMBLY_INSTRUCTIONS.md and README per example.
    - Root README adds a quick-start block and a media-placeholder table for per-example photos/videos.
    - Removed docs/hardware/ (per-example ASSEMBLY_INSTRUCTIONS.md replaces it).
    - Rename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
2026-06-14 docs: restructure README around 3-step workflow; add KABLab acknowledgement; relicense MIT -> GPL-3.0-or-later
    - README rewritten around Mount a Tool -> Define the Deck -> Write a Workflow.
    - Removed redundant 'Starting a New Application' section (now in docs/SETUP.md + per-example READMEs).
    - Authors moved to bottom; added Acknowledgements citing List et al., 'ASMI: An automated, low-cost indenter for soft matter', HardwareX 20, e00601 (2024), DOI 10.1016/j.ohx.2024.e00601.
    - Z calibration helper docs now reference both shipped variants (each example owns its own z_helper.py).
    - LICENSE replaced with full GNU GPL v3 text; pyproject.toml license set to GPL-3.0-or-later.
2026-06-15 docs: populate BOM tables in example ASSEMBLY_INSTRUCTIONS.md from bom.xlsx
    - Add docs/bom.xlsx as the source-of-truth spreadsheet (3 sheets: hello_cnc, liquid_handling_cnc_demo, pick_and_place_cnc_demo).
    - Export each sheet to examples/<name>/bom.csv so the parts list is diffable and renders on GitHub.
    - Replace _TBD_ placeholder rows in liquid_handling and vacuum_pick_and_place ASSEMBLY_INSTRUCTIONS.md with real parts (Genmitsu 3018, Picus 2, vacuum pump, fasteners, 3D-printed parts, etc.).
    - Add examples/hello_cnc/ASSEMBLY_INSTRUCTIONS.md (base-CNC build, ~1 hr) and link it from the hello_cnc and examples READMEs.
    [bom.csv, bom.xlsx]
2026-06-15 docs: rename bom.csv to <example>_bom.csv and gitignore xlsx
    - Rename per-example bom.csv to hello_cnc_bom.csv / liquid_handling_bom.csv / vacuum_pick_and_place_bom.csv so the filename identifies the example when shared/downloaded.
    - Untrack docs/bom.xlsx and gitignore *.xlsx; the per-example CSVs are the tracked source of truth. Update assembly-instruction links and CHANGELOG accordingly.
    [bom.xlsx, hello_cnc_bom.csv, liquid_handling_bom.csv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]
2026-06-15 docs: rename per-example BOM CSVs to match Project field in source spreadsheet
    hello_cnc_bom.csv -> hello_CNC_bom.csv, liquid_handling_bom.csv -> liquid_handling_CNC_demo_bom.csv, vacuum_pick_and_place_bom.csv -> pick_and_place_CNC_demo_bom.csv. Update links in ASSEMBLY_INSTRUC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
    [hello_CNC_bom.csv, liquid_handling_CNC_demo_bom.csv, pick_and_place_CNC_demo_bom.csv]
2026-06-15 docs: drop per-example z_helper.py and smoke-test step
    - Remove examples/liquid_handling/z_helper.py and examples/vacuum_pick_and_place/z_helper.py. The shipped z_heights: in each example's cnc_config.yaml are calibrated for the reference build in its AS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
    - Drop the smoke-test step from liquid_handling and vacuum_pick_and_place READMEs. hello_cnc is a one-time CNC sanity check, not a per-protocol prereq. The standard user journey in examples/README.md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
    - Update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
2026-06-15 README: hero gifs + YouTube links; require Deck(name); drop z_helper/smoke-test prereq
    - README: add side-by-side 5x-speed preview gifs at the top, each linking to its full-length YouTube video; rename Reference-applications 'Photos / videos' column to 'Sample workflow video' with the 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
    - BREAKING: Deck(deck_definition) is now required; no default. Pass 'cnc_4_slot_deck' (Genmitsu 3018), 'cnc_1_slot_deck', or a custom JSON path. Updated examples, README, and docs/SETUP.md.
    - Clarify cnc_4_slot_deck targets the Genmitsu 3018-PROVer V2 footprint (~300x180 mm); larger CNCs should copy and remeasure.
    - Drop per-example z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
2026-06-15 release: 0.9.1 (PyPI-only README)
    Replace the PyPI long_description with a slim, text-only README_PYPI.md focused on the public Python API (CNC_Machine, Deck, DeckState, minimal cnc_config.yaml). The GitHub README.md stays as the rich landing page with hero gifs, reference applications, and the full API reference.
    [100mm-z-spacer.step, 100mm-z-spacer.stl, deck-slot-5mm-offset.step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]
2026-06-15 cad: distribute STL/STEP files per-example under cad/{step,stl}/
    Replace the top-level '3d printing files/' dump with per-example cad/ folders. Each example is self-contained; deck-slot-standard and M6_thumb_screw are duplicated across both examples (<1 MB total). Also fix three filename typos in ASSEMBLY_INSTRUCTIONS.md (deck-slot-5mm-taller -> deck-slot-5mm-offset, M6-thumb-screws -> M6_thumb_screw, suction-cup-holder -> suction_cup_holder) and make every BOM print-row a clickable link to its cad/stl/ file.
    [100mm-z-spacer.step, 100mm-z-spacer.stl, M6_thumb_screw.step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]
2026-06-15 cad: normalize CAD filenames to lowercase kebab-case
    Renamed M6_thumb_screw -> m6-thumb-screw, suction_cup_holder -> suction-cup-holder, sartorius_24_tiprack_5000ul -> sartorius-24-tiprack-5000ul, sartorius-5000uL-pipette-tool-holder-{A,B} -> sartorius-5000ul-pipette-tool-holder-{a,b}. Updated both ASSEMBLY_INSTRUCTIONS.md files and both BOM CSVs to match.
    The Opentrons labware load name 'sartorius_24_tiprack_5000ul' (custom_labware/*.json, cnc_config.yaml comments, deck_preset.yaml comments) is intentionally left snake_case -- that's the Opentrons load-name convention and the JSON filename must match the loadName field for load_definition() to resolve it.
    [liquid_handling_CNC_demo_bom.csv, m6-thumb-screw.step, m6-thumb-screw.stl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]
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2026-06-15 pick_and_place: add storage + gameboard CAD; align names with labware JSON
    Added storage-15-tuberack-100ul.{step,stl} and gameboard-15-tuberack-100ul.{step,stl} under examples/vacuum_pick_and_place/cad/. Filenames now mirror the matching Opentrons loadName so JSON <-> CAD pairing is unambiguous (also fixed an existing tic-tac-toe-board.stl vs tic-tac-toe-game-board.step inconsistency). BOM (B6/B7), ASSEMBLY_INSTRUCTIONS Stage 2 wording, and README deck-layout table updated; slots corrected to storage=3 / gameboard=4 to match tools/cnc_config.yaml (README was the stale doc).
    [gameboard-15-tuberack-100ul.step, gameboard-15-tuberack-100ul.stl, pick_and_place_CNC_demo_bom.csv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]
